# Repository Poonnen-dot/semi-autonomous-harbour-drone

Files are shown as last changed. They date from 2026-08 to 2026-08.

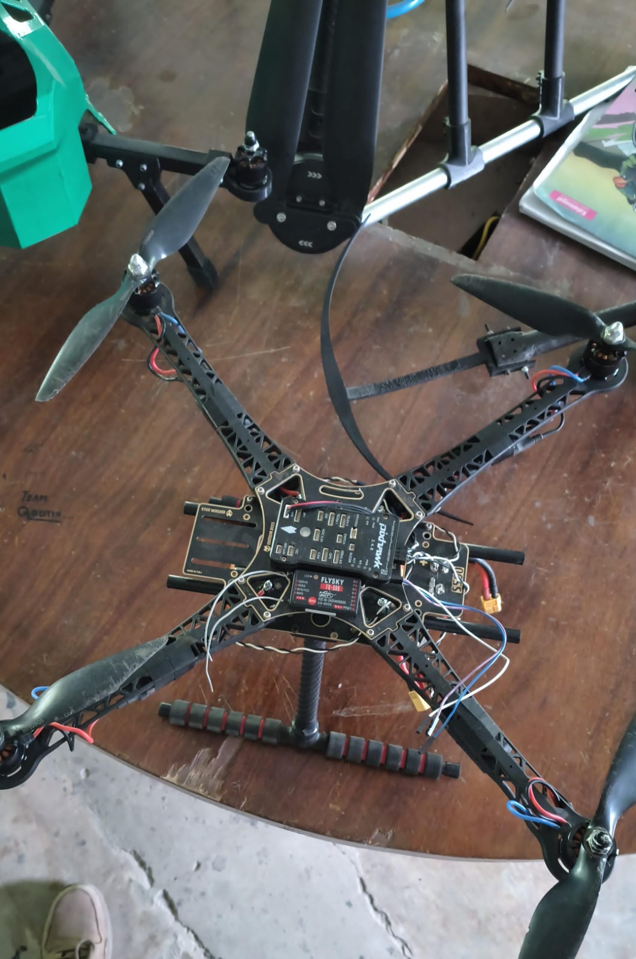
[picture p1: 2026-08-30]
media/build-photos-videos/FORGE DRONE ASSEMBLY PROGRESS PICTURES (13).jpeg

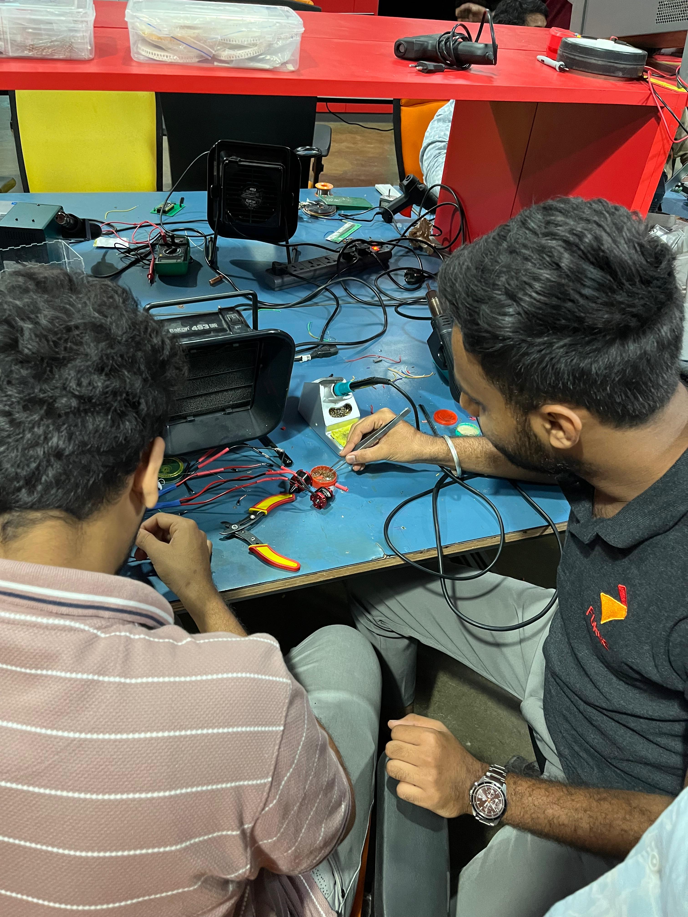
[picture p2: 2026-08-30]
media/build-photos-videos/FORGE DRONE ASSEMBLY PROGRESS PICTURES (4).jpeg

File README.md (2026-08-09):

# Semi-Autonomous Drone for Harbour Logistics

## Overview

A semi-autonomous quadcopter developed for harbour logistics and surveillance applications. The system integrates flight control, GPS navigation, telemetry, sensing, propulsion, and payload capabilities into a single aerial platform.

The project was developed as a practical mechatronics system, involving mechanical assembly, electronics integration, flight-controller configuration, embedded hardware, autonomous mission planning, troubleshooting, and flight testing.

## Objectives

- Develop a stable quadcopter platform for harbour applications
- Implement GPS-based navigation
- Enable semi-autonomous flight and mission planning
- Integrate telemetry for ground-station communication
- Integrate range sensing
- Develop a mechanism for payload transportation
- Test the system under practical flight conditions

## My Role

### Project Lead / Technical Lead

I was responsible for the technical development and system integration of the drone. My responsibilities included:

- System architecture and component selection
- Airframe and propulsion-system integration
- Pixhawk flight-controller configuration
- ESC and motor configuration
- GPS and telemetry integration
- ArduPilot and Mission Planner configuration
- Hardware troubleshooting and debugging
- Flight testing and system validation
- Coordinating and guiding team members during implementation

## System Architecture

The system consists of:

- Pixhawk flight controller
- GPS module
- 4-in-1 ESC
- Four brushless motors
- LiPo battery
- RC transmitter and receiver
- Telemetry system
- Range sensor
- Payload mechanism

## Hardware

| Component | Model | Purpose |
|---|---|---|
| Flight Controller | Pixhawk 2.4.8 | Flight control |
| Frame | S500 | Airframe |
| Motors | ReadyToSky 2212 920KV | Propulsion |
| ESC | Velox 50A 4-in-1 | Motor control |
| Battery | 4S 6200mAh | Power |
| GPS | u-blox NEO-M9N | Navigation |
| RC System | FlySky FS-i6X | Manual control |
| Range Sensor | Benewake TFmini Plus | Distance sensing |
| Telemetry | T10 Simplify | Ground communication |

## Software

- ArduPilot
- Mission Planner
- Pixhawk firmware/configuration
- Mission planning and flight testing

## Development Process

The project followed an iterative development process:

1. System requirements definition
2. Component selection
3. Mechanical assembly
4. Electrical integration
5. Flight-controller configuration
6. Motor and ESC testing
7. GPS and telemetry integration
8. Troubleshooting
9. Flight testing
10. System refinement

## Testing

The drone was assembled and successfully flight-tested. Testing involved:

- Motor direction verification
- ESC and motor testing
- Flight-controller configuration
- GPS verification
- Telemetry verification
- Battery and power-system testing
- Flight stability testing
- Troubleshooting of motor and flight-controller issues

## Lessons Learned

The project provided practical experience in:

- Multirotor system integration
- Embedded hardware
- Flight-control systems
- Sensor integration
- Electrical troubleshooting
- Hardware-software integration
- System-level debugging
- Engineering testing and validation

## Project Status

Prototype successfully assembled and flight-tested.

Further development can include improved autonomy, payload handling, obstacle avoidance, and advanced navigation capabilities.

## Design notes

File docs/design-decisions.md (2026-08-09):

# Engineering Design Decisions

This document records the engineering calculations and design decisions used during the development of the propulsion system.

The calculations represent theoretical design estimates used for component selection. Actual flight performance was subsequently evaluated through ground and flight testing.

---

## 1. Propulsion Design Requirements

The propulsion system was designed around an estimated Maximum Take-Off Weight (MTOW) of:

**MTOW = 1.7 kg**

A design thrust-to-weight ratio of:

**T/W = 2.15**

was selected to provide sufficient thrust margin for a multirotor platform carrying additional equipment and payload.

---

## 2. Required Total Thrust

The required total thrust was calculated as:

**T = MTOW × (T/W)**

Therefore:

**T = 1.7 × 2.15**

**T = 3.655 kgf**

For a four-motor quadcopter:

**Thrust per motor = 3.655 / 4**

**= 0.91375 kgf ≈ 1 kgf per motor**

Therefore, the propulsion system was designed around approximately **1 kgf of required thrust per motor**.

### Calculation

Thrust-to-weight ratio calculation

---

## 3. Propeller Disk Area

The required propeller disk area was estimated using the thrust relationship:

**T = 1/2 × ρ × (Ve² − Vi²) × Ap**

where:

- ρ = 1.225 kg/m³
- Ve = 16 m/s
- Vi = 3 m/s
- T = 9.1375 N

Substitution gives:

**Ap = 0.060398 m²**

### Calculation

Propeller area calculation

---

## 4. Propeller Diameter

Using the calculated propeller disk area:

**A = πr²**

The required radius was calculated as:

**r = √(A/π)**

which gives:

**r = 0.1386 m**

or approximately:

**r = 5.4 inches**

Therefore:

**D = 2r = 10.8 inches**

A commercially available **10-inch propeller** was selected as the nearest practical standard size.

### Calculation

Propeller radius and diameter calculation

---

## 5. Propeller Pitch Selection

The pitch-to-diameter ratio was selected as:

**P/D = 0.4**

Using the calculated diameter:

**D = 10.8 inches**

Therefore:

**P = 10.8 × 0.4**

**P = 4.32 inches**

A standard **4.5-inch pitch** was selected as the nearest practical option.

The resulting selected propeller specification was:

**10 × 4.5 inches**

### Calculation

Propeller pitch calculation

---

## 6. Lift Coefficient Estimate

The lift coefficient was estimated using:

**L = 1/2 × ρ × Ve² × Ap × Cl**

Rearranging:

**Cl = L / (1/2 × ρ × Ve² × Ap)**

Using the calculated parameters gave:

**Cl ≈ 0.96**

This calculation was used as part of the preliminary aerodynamic assessment of the selected propeller geometry.

### Calculation

Lift coefficient calculation

---

## 7. Hover RPM Estimate

The required propeller rotational speed was estimated using the RPM-based thrust relationship.

The resulting calculated value was:

**RPM ≈ 6069 RPM**

This represents a **theoretical hover RPM estimate** under the assumptions used in the calculation. It should not be interpreted as a directly measured flight value.

### Calculation

Hover RPM calculation

---

## 8. Final Propulsion Selection

Based on the preceding calculations, the prototype propulsion system was configured with:

| Component | Selected Specification |
|---|---|
| Frame | S500 |
| Motor | 2212 920KV brushless motor |
| Propeller | 10 × 4.5 inch |
| ESC | Velox 50A 4-in-1 |
| Battery | 4S 6200mAh LiPo |
| Number of motors | 4 |
| Estimated MTOW | 1.7 kg |
| Design thrust-to-weight ratio | 2.15 |
| Required total thrust | 3.655 kgf |
| Required thrust per motor | 0.91375 kgf |

---

## 9. Engineering Validation

The calculations above were used for preliminary system sizing and component selection.

The actual prototype was then assembled and subjected to:

- Motor and ESC testing
- Flight-controller configuration
- Propulsion-system testing
- Ground testing
- Initial flight testing
- Troubleshooting of motor and ESC behaviour
- Flight validation

The theoretical calculations therefore served as the **design basis**, while physical testing was used to evaluate the behaviour of the completed system.

---

## 10. Design Approach

The propulsion system was not selected solely from commercially available components. The selection process began with system requirements and theoretical calculations, followed by practical component selection and physical validation.

The overall engineering sequence was:

**Requirement → Calculation → Component Selection → Integration → Ground Testing → Flight Testing → Troubleshooting**

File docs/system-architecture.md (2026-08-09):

# System Architecture

## Overview

The drone is designed as an integrated mechatronic system consisting of flight control, propulsion, power, navigation, communication, sensing, and payload subsystems.

## Major Subsystems

### 1. Flight Control
- Pixhawk 2.4.8
- ArduPilot firmware
- Mission Planner ground-control software

### 2. Propulsion
- S500 quadcopter frame
- Four 2212 920KV brushless motors
- Velox 50A 4-in-1 ESC
- 10 × 4.5 inch propellers

### 3. Power System
- 4S 6200 mAh LiPo battery
- Power distribution system
- Pixhawk power module

### 4. Navigation
- u-blox NEO-M9N GPS
- GPS-based position estimation
- Mission Planner waypoint planning

### 5. Communication
- FlySky FS-i6X transmitter
- FS-IA10B receiver
- T10 telemetry system

### 6. Sensing
- Benewake TFmini Plus range sensor
- GPS position data
- Flight-controller IMU and onboard sensors

### 7. Payload
- Payload mechanism designed for logistics applications

## High-Level Data Flow

                         Ground Station
                              │
                         Telemetry Link
                              │
                              ▼
GPS ──────────────────► Pixhawk 2.4.8 ◄──────── RC Receiver
                              │
                    ┌─────────┴─────────┐
                    │                   │
                    ▼                   ▼
               4-in-1 ESC          Range Sensor
                    │
             ┌──────┼──────┬──────┐
             ▼      ▼      ▼      ▼
            M1     M2     M3     M4
             │      │      │      │
             └──────┴──────┴──────┘
                       │
                  Propulsion

Battery ───────► Power Distribution
                       │
                       ├────► ESC
                       └────► Pixhawk Power Module

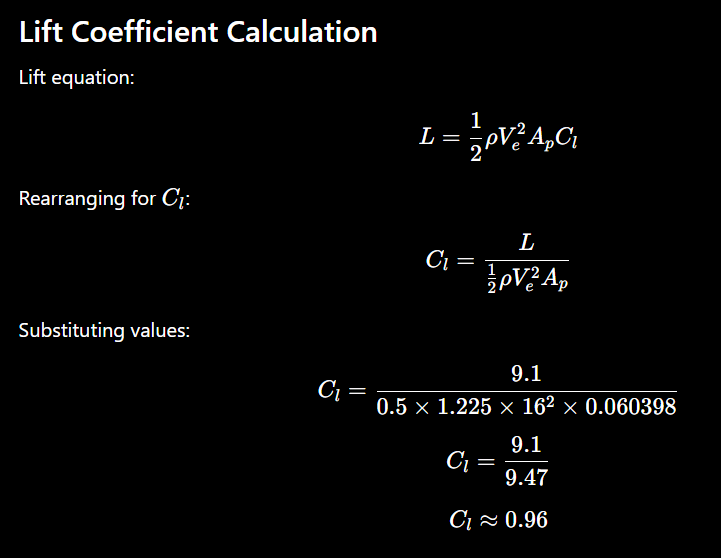
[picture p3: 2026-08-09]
calculations/Screenshot 2026-05-26 155852.png

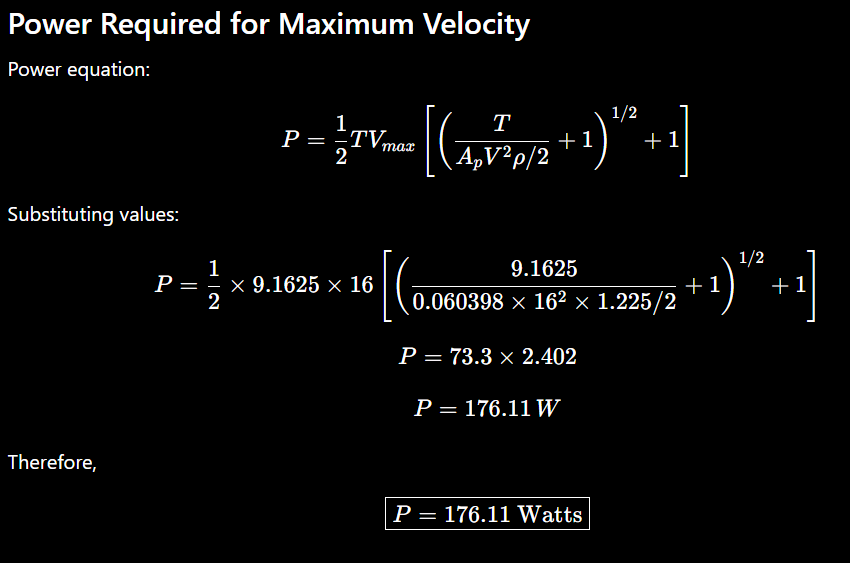
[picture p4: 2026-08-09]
calculations/Screenshot 2026-05-26 155919.png

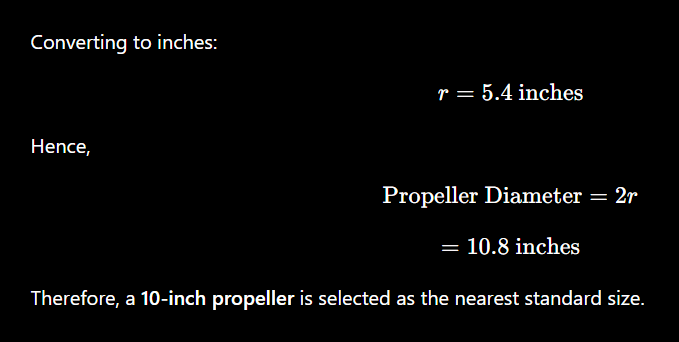
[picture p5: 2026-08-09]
calculations/Screenshot 2026-05-26 155834.png

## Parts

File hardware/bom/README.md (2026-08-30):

# Bill of Materials

This folder contains the complete Bill of Materials (BOM) used to build the semi-autonomous harbour logistics drone.

The BOM includes:

- Frame
- Flight controller
- Motors
- ESC
- Battery
- GPS
- Telemetry
- RC system
- Sensors
- Fasteners
- Connectors

The BOM was used during procurement and assembly to ensure component compatibility and project reproducibility.

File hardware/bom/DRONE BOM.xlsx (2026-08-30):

Product Innovation |  | Tracked Bot
Innovation Team |  | Sentinels
# | Components | Specifications | Prototyping Expense (PE) Type | Unit Price | Qty | Existing Inventory (Yes/No) | Existing Inventory Cost (INR) | New Purchase Cost (INR) | Budgeted Expenses (Value) (INR) | Asset Cost (INR) | Reusable Cost (INR) | Consumable Cost(INR) | Actual Expenses (Cost) (INR) | Remarks | Product Link
Prototype Development |  |  |  |  | 25200 |  | 40500 | 0 | 40500 | 0 | 40500
1 | Frame | S500 Quadcopter Frame | Reusable | ₹3000 | 1 | Yes | 3000 | 0 | 3000 | 0 | 3000 | 0 | 3000 |  | LINK (https://evelta.com/s500-quadcopter-pcb-frame-kit-carbon-fiber-landing-gear/)
2 | Flight Controller | Pixhawk 2.4.8 | Reusable | ₹6500 | 1 | Yes | 6500 | 0 | 6500 | 0 | 6500 | 0 | 6500 |  | LINK (https://robu.in/product/l298-based-motor-driver-module-2a/)
3 | GPS Module | M9 GNSS | Reusable | ₹2500 | 1 | Yes | 2500 | 0 | 2500 | 0 | 2500 | 0 | 2500 |  | LINK (https://robu.in/product/gps-glonass-gnss-antenna-for-raspberry-pi-hat-and-arduino-shield-with-3-meter-cable/)
4 | Telemetry | T10 433 MHz | Reusable | ₹3000 | 1 | No | 0 | 3000 | 3000 | 0 | 3000 | 0 | 3000 |  | LINK (https://robu.in/product/raspberry-pi-4-model-b-with-8-gb-ram/)
5 | Compute | Raspberry Pi 5 (8GB) | Reusable | ₹9000 | 1 | Yes | 9000 | 0 | 9000 | 0 | 9000 | 0 | 9000 |  | LINK (https://robu.in/product/waveshare-rpi-camera-b-adjustable-focus/)
6 | Camera | Raspberry Pi Camera v3 | Reusable | ₹3000 | 1 | Yes | 3000 | 0 | 3000 | 0 | 3000 | 0 | 3000 |  | LINK (https://robu.in/product/rp-lidar-a1m8-360-degrees-laser-range-finder/)
7 | Motors | 2212 920KV Brushless | Reusable | ₹1200 | 1 | No | 0 | 1200 | 1200 | 0 | 1200 | 0 | 1200 |  | LINK (https://robu.in/product/1-month-warranty-524/)
8 | ESC | 4-in-1 ESC | Reusable | ₹6000 | 1 | No | 0 | 6000 | 6000 | 0 | 6000 | 0 | 6000 |  | LINK (https://robu.in/product/65mm-robot-smart-car-wheel-for-bo-motors-green/)
9 | Propellers | 10–11 inch | Reusable | ₹800 | 1 | No | 0 | 800 | 800 | 0 | 800 | 0 | 800 |  | LINK (https://www.amazon.in/2600mAh-Lithium-Ion-Battery-Rechargeable-Projects/dp/B0G2H8KSX6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)
10 | Battery | 4S LiPo 5000mAh | Reusable | ₹3500 | 1 | No | 0 | 3500 | 3500 | 0 | 3500 | 0 | 3500 |  | LINK (https://robu.in/product/esp-wroom-32-mcu-module-without-ble/)
11 | Power Module | Pixhawk PM V6 | Reusable | ₹1200 | 1 | Yes | 1200 | 0 | 1200 | 0 | 1200 | 0 | 1200 |  | LINK (https://robu.in/product/ams1117-3-3v-1a-sot-223-voltage-regulator-ic-pack-of-5-ics/)
12 | Payload Box | 3D Printed PETG | Reusable | ₹800 | 1 | No | 0 | 800 | 800 | 0 | 800 | 0 | 800 |  | LINK (https://robu.in/product/level-converter-4-channel/)
 |  |  |  |  | 14
 |  | Total Budgeted Expenses | 40500
 |  | Existing Inventory Utilized | 25200
 |  | Total New Purchase Cost
 | Prepared | Reviewer 1 | Reviewer 2 | Approved
 | <Name> | <Name> | <Name> | David
 | Team Visionary | Team SPoC | Cohort Lead | MUP Owner
 | FALSE | FALSE | FALSE | FALSE

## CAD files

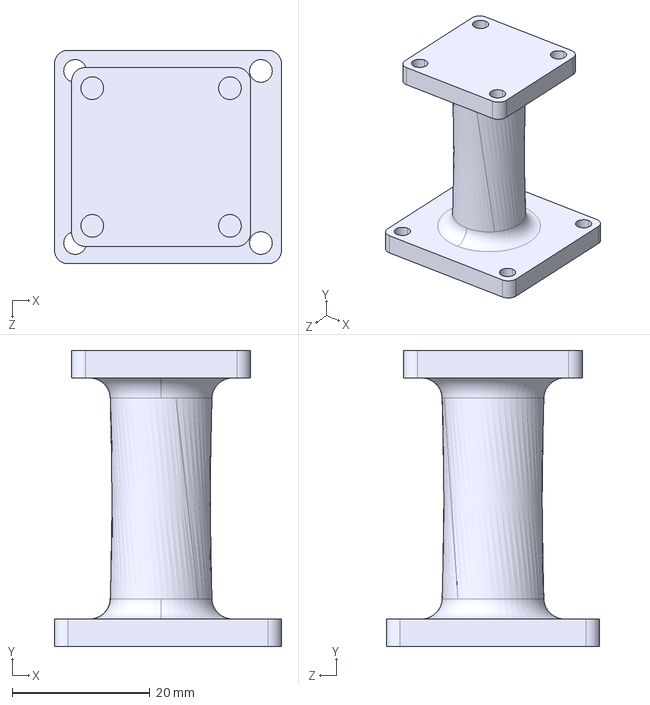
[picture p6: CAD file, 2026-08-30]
docs/cad/step-files/suppport.STEP
33.0 x 43.0 x 31.0 mm

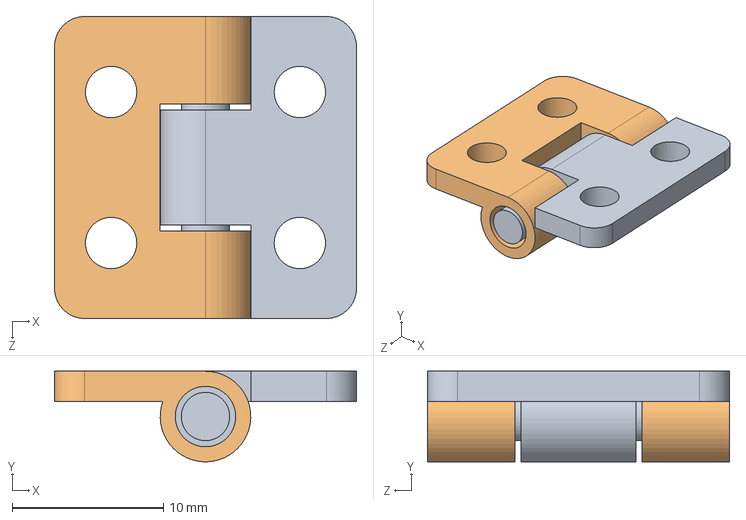
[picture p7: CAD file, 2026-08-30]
docs/cad/step-files/20x20 3D Print Hinge.STEP
20.0 x 5.99 x 20.0 mm

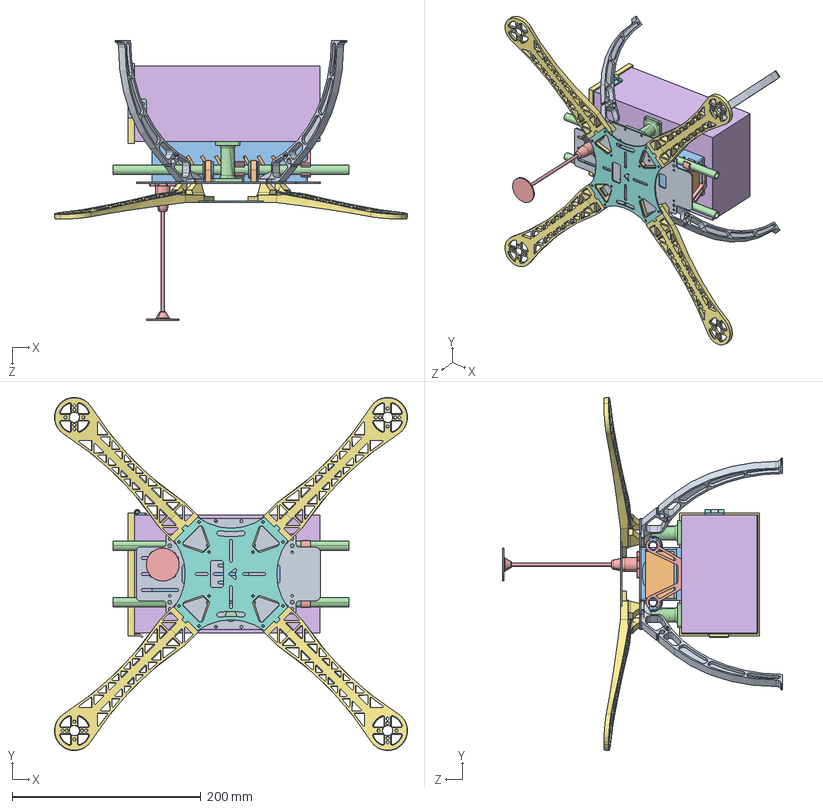
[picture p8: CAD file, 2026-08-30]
docs/cad/step-files/S500 Frame.STEP
374.3 x 374.3 x 296.4 mm
Bottom Plate.stp
Rail Support.stp x 4
Rail Support Grommet.stp x 4
Rail.stp x 2
Battery Plate Support.stp x 2
Battery Plate.stp
Arm - White.stp x 2
Arm - Blue.stp x 2
Top Plate.stp
Leg.stp x 4
Socket
suppport x 3
GPS MODÜLÜ 0SKELET0_Varsayılan
box cap
20x20 3D Print Hinge.step

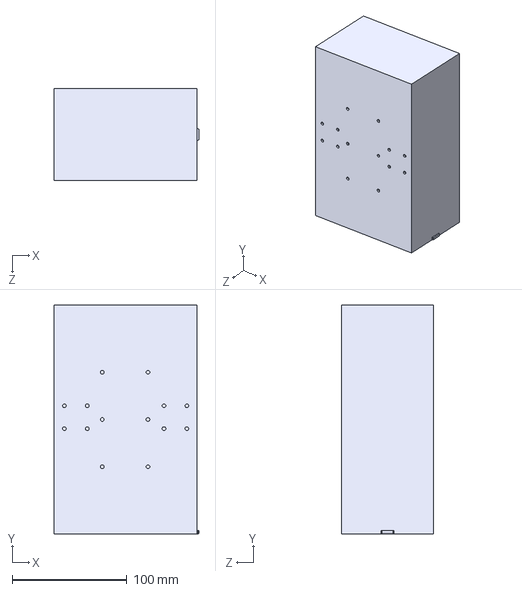
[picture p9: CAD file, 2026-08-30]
docs/cad/step-files/box.STEP
126.5 x 200.0 x 80.0 mm

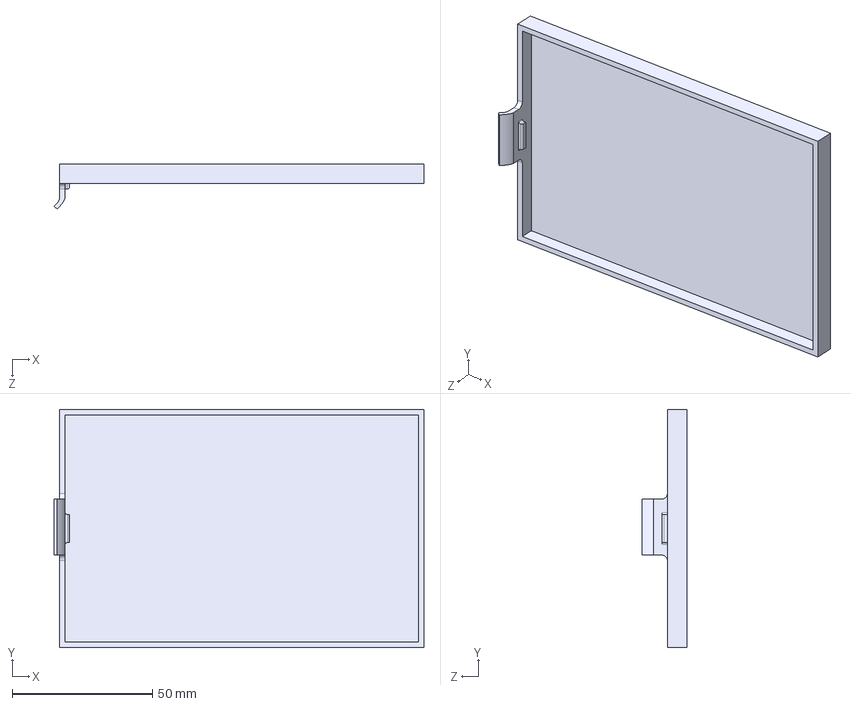
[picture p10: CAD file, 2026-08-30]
docs/cad/step-files/box cap.STEP
132.0 x 85.0 x 16.1 mm

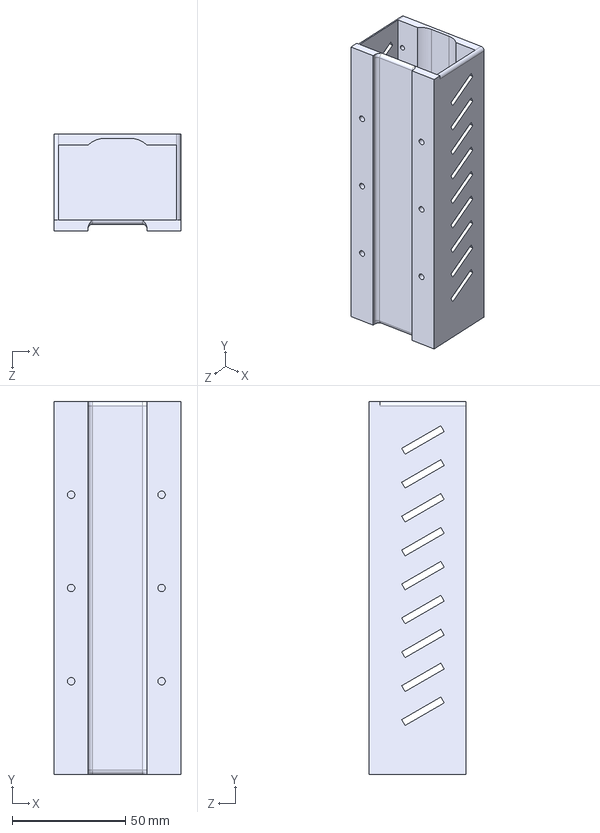
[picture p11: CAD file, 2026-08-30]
docs/cad/step-files/Socket.STEP
56.0 x 165.0 x 43.0 mm

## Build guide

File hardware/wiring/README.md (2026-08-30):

# Wiring Overview

The electrical system consists of:

- Pixhawk 2.4.8 Flight Controller
- Velox 50A 4-in-1 ESC
- 4 × 2212 920KV Brushless Motors
- 4S 6200mAh LiPo Battery
- NEO-M9N GPS
- FlySky FS-IA10B Receiver
- T10 Telemetry Module
- TFMini Plus Range Sensor

The battery powers the propulsion system through the ESC while the Pixhawk receives regulated power from the power module.

The Pixhawk communicates with:

- GPS
- RC Receiver
- Telemetry
- ESC
- Range Sensor

Future versions of this repository will include detailed wiring diagrams and pin assignments.

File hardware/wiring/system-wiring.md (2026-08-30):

# System Wiring

4S LiPo Battery
        │
        ▼
Power Module
        │
        ▼
Pixhawk 2.4.8
        │
        ├──────── GPS
        ├──────── Telemetry
        ├──────── RC Receiver
        ├──────── TFMini Plus
        │
        ▼
4-in-1 ESC
        │
 ┌──────┼──────┬──────┐
 ▼      ▼      ▼      ▼
M1     M2     M3     M4

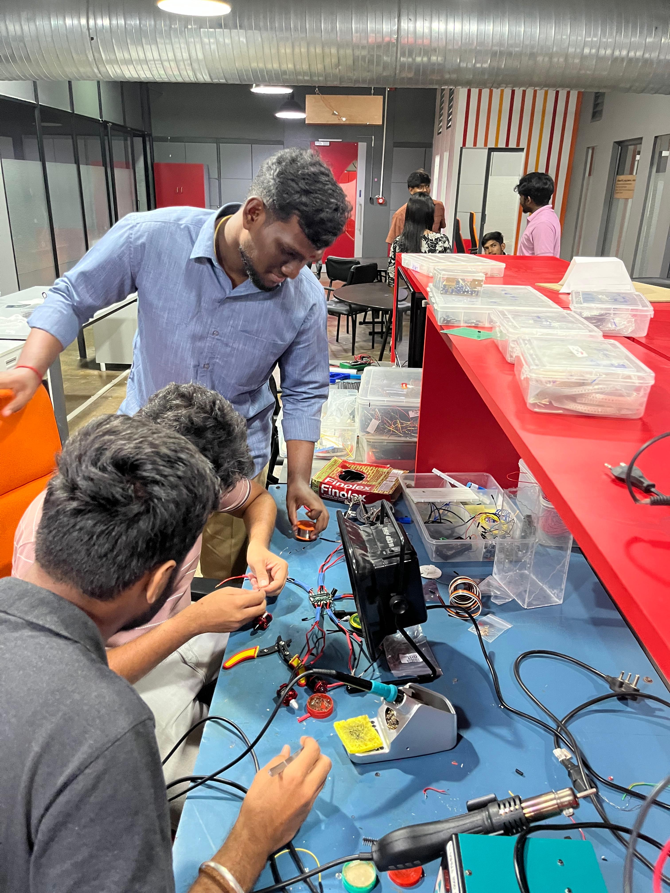
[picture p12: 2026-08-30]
media/build-photos-videos/FORGE DRONE ASSEMBLY PROGRESS PICTURES (11).jpeg
